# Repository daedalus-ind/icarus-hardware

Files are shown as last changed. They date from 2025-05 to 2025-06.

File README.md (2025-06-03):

# Icarus Flight Computer V1.0

This repository contains the hardware design files for the version 1.0 of the flight computer developed for Project Icarus, a model rocket.

## 📸 Photos

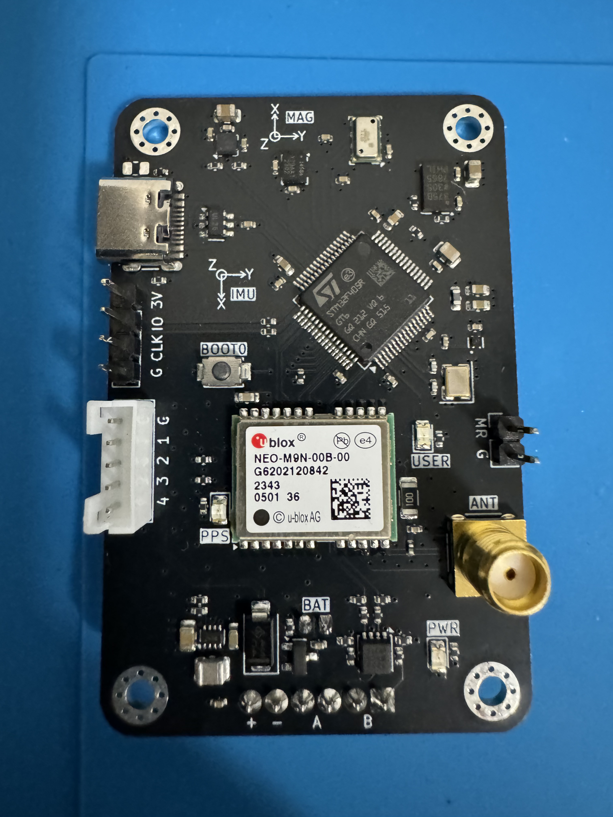
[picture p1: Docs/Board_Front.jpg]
Icarus Flight Computer V1.0 Front Size

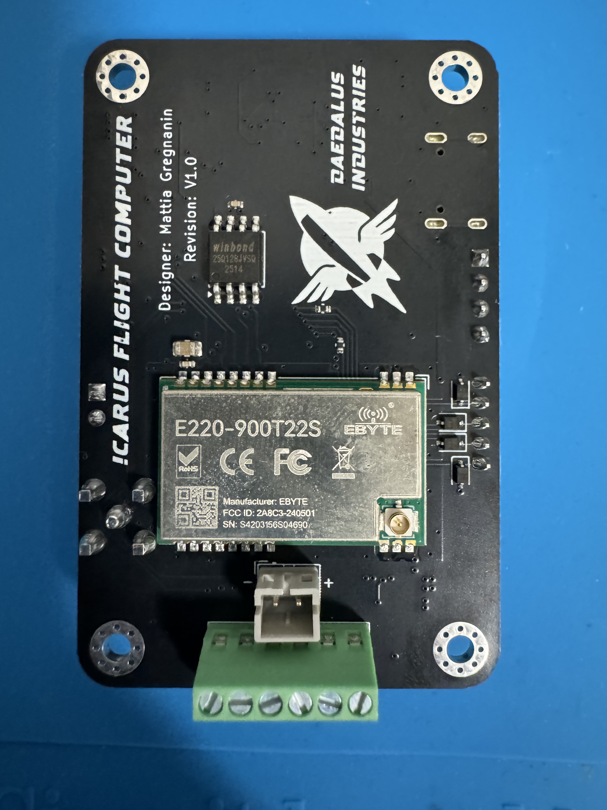
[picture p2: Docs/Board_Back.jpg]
Icarus Flight Computer V1.0 Back Side


## 🧰 Overview 

The Icarus Flight Computer V1.0 is designed to manage data acquisition, telemetry, and flight event control during rocket missions. The board includes:
- **Microcontroller**: STMicroelectronics STM32F405RGT6
- **6-Axis IMU**: TDK InvenSense ICM-45686
- **High-G Accelerometer**: Analog Devices ADXL375
- **Magnetometer**: STMicroelectronics LIS2MDL
- **Barometer**: MEAS MS5607
- **GPS Module**: u-blox NEO-M9N
- **Radio Module**: EBYTE E220-900T22S
- **Flash Memory**: Windbond W25Q128JV
- **E-matches**: 2x electric matches for recovery system deployment
- **Power Management**: TPS631000 buck-boost converter
- **Power Supply**: 1S LiPo battery or USB-C power input

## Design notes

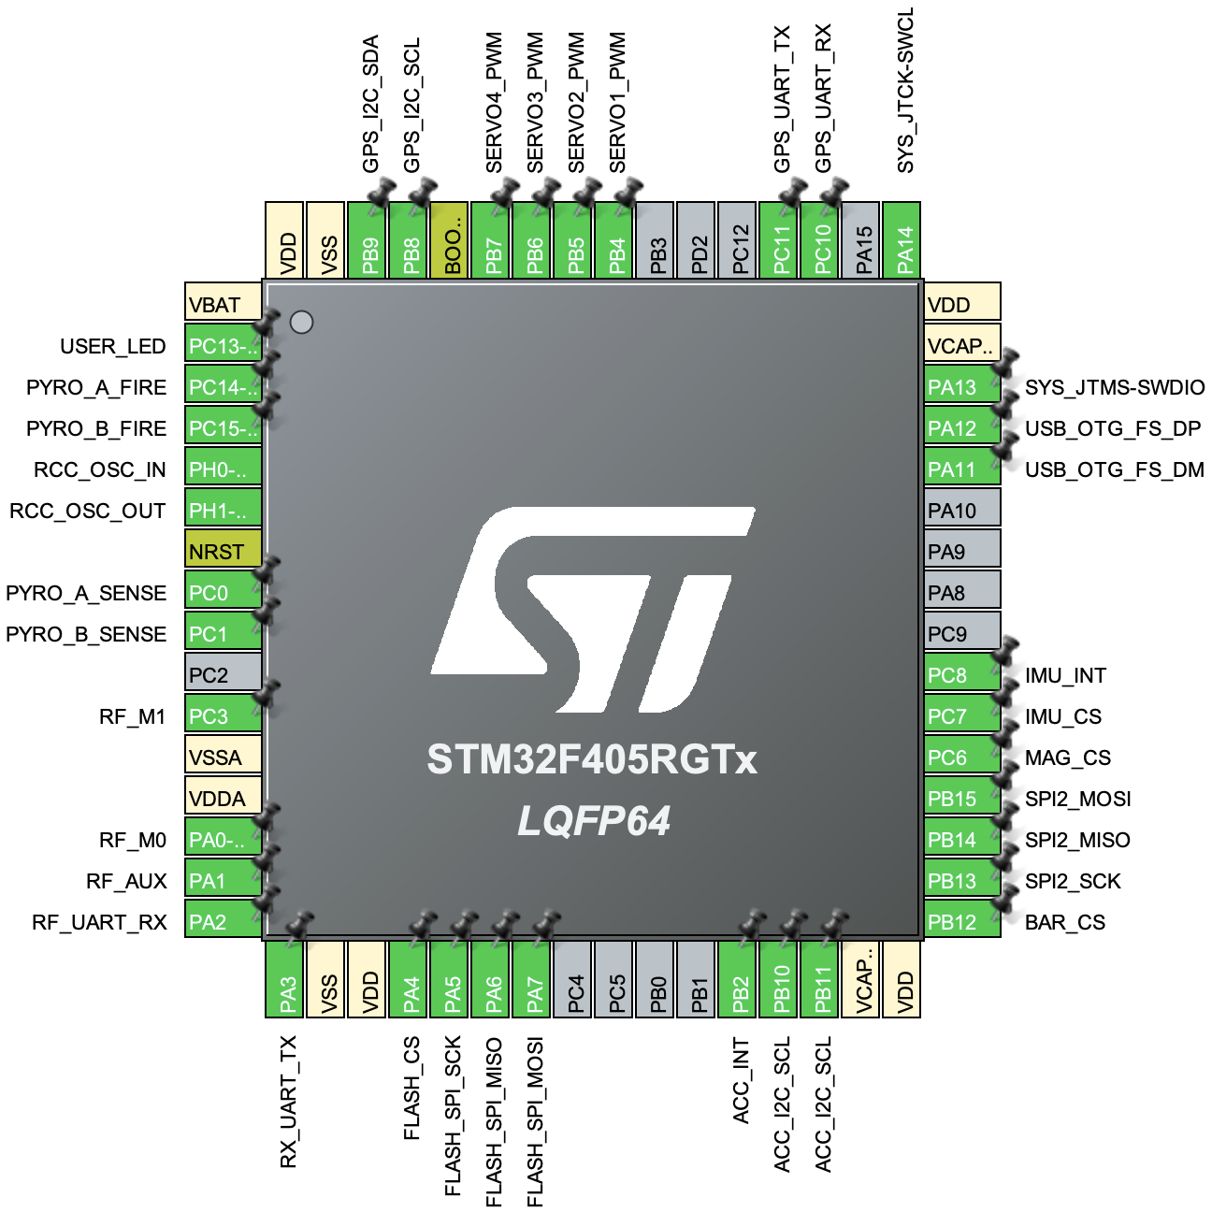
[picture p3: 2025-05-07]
STM32F405RGT6 Schematic.png

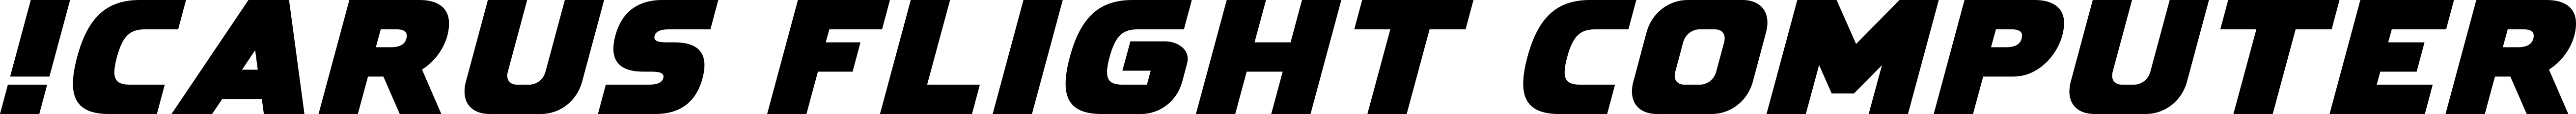
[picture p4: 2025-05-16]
IcarusFlightComputer-White-300dpi.png

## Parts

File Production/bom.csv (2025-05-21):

Designator | Footprint | Quantity | Value | LCSC Part #
C1, C23, C29, C35 | 0805 | 4 | 10u | C95841
C10, C15, C16, C17, C18, C2, C21, C22, C24, C25, C26, C27, C28, C3, C30, C31, C34, C36, C37, C4, C5, C6 | 0402 | 22 | 100n | C1525
C11, C12 | 0402 | 2 | 10p | C32949
C13, C14 | 0603 | 2 | 2u2 | C23630
C19 | 0805 | 1 | 47u | C471380
C20 | 0603 | 1 | 10u | C90053
C32 | 0402 | 1 | 220n | C16772
C33, C7, C8 | 0603 | 3 | 1u | C59782
C9 | 0402 | 1 | 10n | C318577
D1, D2, D4 | 0805 | 3 | RED | C84256
D3 | D_SMA | 1 | SS14 | C47460
D5, D6, D7, D8 | D_SOD-323 | 4 | PESD3V3L1BA | C51450
FB1 | 0603 | 1 | 120R | C85831
J1 | PinHeader_1x04_P2.54mm_Vertical | 1 | Conn_01x04_Pin | C2691448
J2 | USB_C_Receptacle_G-Switch_GT-USB-7010ASV | 1 | USB_C_Receptacle_USB2.0_14P | C2988369
J3 | JST_PH_B2B-PH-K_1x02_P2.00mm_Vertical | 1 | JST PH 2.0 | C2683610
J4 | PinHeader_1x02_P2.54mm_Vertical | 1 | Conn_01x02_Pin | C492401
J5 | SMA_Amphenol_132134_Vertical | 1 | SMA | C3174425
J6 | TerminalBlock_Phoenix_MPT-0,5-6-2.54_1x06_P2.54mm_Horizontal | 1 | Screw_Terminal_01x06 | C3817456
J7 | JST_PH_B5B-PH-K_1x05_P2.00mm_Vertical | 1 | JST PH 2.0 | C157993
L1 | 1008 | 1 | 1u | C882955
L2 | 0402 | 1 | 27n | C12669
Q1 | SOT-23 | 1 | DMG2305UX | C150470
Q2 | Vishay_PowerPAK_1212-8_Dual | 1 | Si7232DN | C144854
R1, R2 | 0402 | 2 | 22R | C25092
R10, R11 | 0402 | 2 | 5k1 | C25905
R13 | 0402 | 1 | 511k | C64042
R14, R18, R20, R24, R5 | 0402 | 5 | 1k | C11702
R15 | 0402 | 1 | 91k | C4147
R16, R19, R23 | 0402 | 3 | 100k | C25741
R17 | 1206 | 1 | 10R | C25349
R21, R25 | 0402 | 2 | 27k | C25771
R22, R26, R3, R4 | 0402 | 4 | 10k | C25531
R27, R28, R29, R30 | 0402 | 4 | 47R | C25118
R6, R7, R8, R9 | 0402 | 4 | 2k | C4109
SW1 | SW_TS-1088-AR02016 | 1 | SW_Push | C720477
U1 | LQFP-64_10x10mm_P0.5mm | 1 | STM32F405RGT6 | C15742
U10 | ublox_NEO | 1 | NEO-M9N-00B | C5119087
U11 | E220-xxxT22S | 1 | E220-900T22S | C970285
U2 | SOIC-8_5.3x5.3mm_P1.27mm | 1 | W25Q128JVSIQ | C97521
U3 | SOT-23-6 | 1 | USBLC6-2SC6 | C7519
U4 | Texas_X2SON-4_1x1mm_P0.65mm | 1 | TPS3831G33DQNR | C2066649
U5 | SOT-583-8 | 1 | TPS631000 | C5219190
U6 | LGA-14_3x2.5mm_P0.5mm_LayoutBorder3x4y | 1 | ICM-45686 | C22459454
U7 | LGA-14_3x5mm_P0.8mm_LayoutBorder1x6y | 1 | ADXL375 | C579466
U8 | LGA-12_2x2mm_P0.5mm | 1 | LIS2MDL | C919695
U9 | MS5607-02BA03 | 1 | MS5607-02BA | C97627
Y1 | Crystal_SMD_3225-4Pin_3.2x2.5mm | 1 | 16MHz | C112972

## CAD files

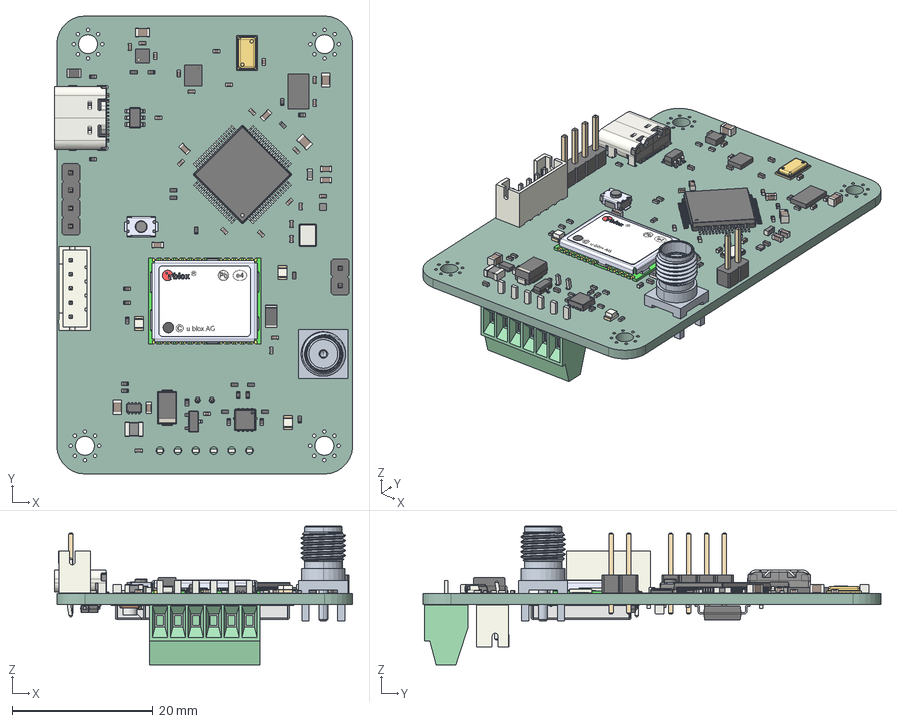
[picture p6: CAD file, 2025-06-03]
Docs/Icarus Flight Computer.step
42.4 x 65.0 x 19.7 mm
R_0402_1005Metric x 28
R_0805_2012Metric
NEO_PCB
Shield_NEO
u-blox_NEO_label
C_0603_1608Metric x 6
C_0402_1005Metric x 26
LGA-14_3x2.5mm_P0.5mm_LayoutBorder3x4y
LED_0805_2012Metric x 3
L_0603_1608Metric
PowerPAK_1212_Dual
LGA-14_3x5mm_P0.8mm_LayoutBorder1x6y
Crystal_SMD_3225-4Pin_3.2x2.5mm
L_1008_2520Metric
R_1206_3216Metric
C_0805_2012Metric x 5
SOT-23-6
SOT-583-8
D_SMA
SOT-23
L_0402_1005Metric
TS-1088-AR02016
PinHeader_1x02_P2.54mm_Vertical
PinHeader_1x04_P2.54mm_Vertical
JST_PH_B5B-PH-K_1x05_P2.00mm_Vertical
Texas_X2SON-4_1x1mm_P0.65mm
SMA_Amphenol_132134
LGA-12_2x2mm_P0.5mm
LQFP-64_10x10mm_P0.5mm
Imported
USB_C_Receptacle_GCT_USB4105-xx-A_16P_TopMnt_Horizontal
D_SOD-323 x 4
Board
CAPC1005X56N_EIA_0402 x 35
User_Library-RESC0603X___ x 7
R0402 x 7
User_Library-SOT23-5_SOT23-5_Connector_Default x 10
User_Library-SOT23-5_SOT23-5_Body_Default x 2
User_Library-GeyerElectronics_KX7
User_Library-Chip_InductorINDC1005X60N x 8
INDC2012X105N_EIA_0805
CAPC1608X92N_EIA_0603 x 2
ANT-IPEX-1
PBZ-43
JST_PH_B2B-PH-K_1x02_P2.00mm_Vertical
TerminalBlock_Phoenix_MPT-0,5-6-2.54_1x06_P2.54mm_Horizontal
SOIC-8_5.3x5.3mm_P1.27mm
Icarus Flight Computer_PCB

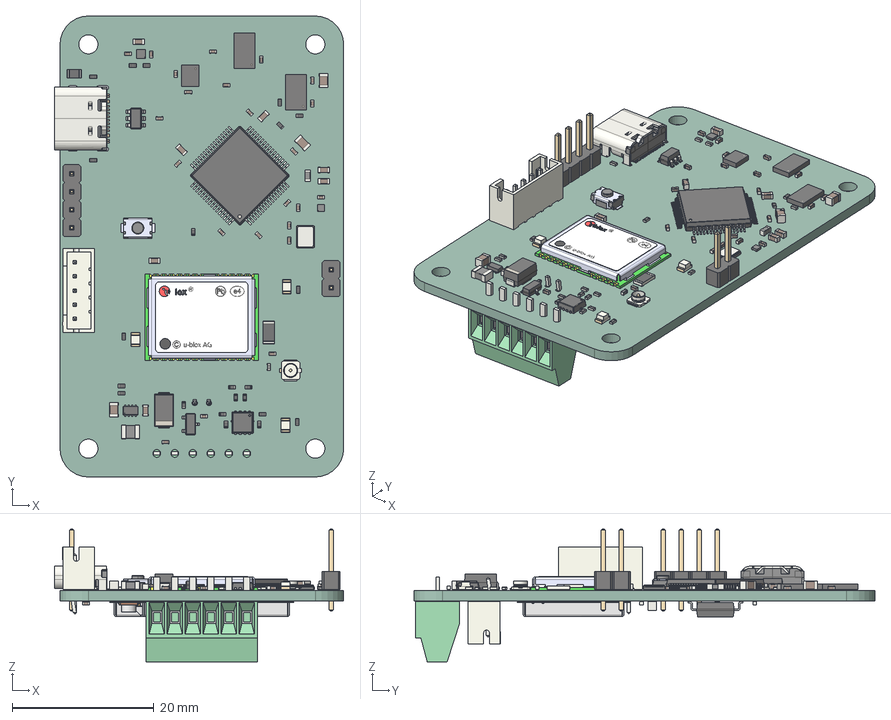
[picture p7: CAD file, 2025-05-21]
Icarus Flight Computer.step
40.8 x 65.0 x 18.7 mm
R_0805_2012Metric
NEO_PCB
Shield_NEO
u-blox_NEO_label
C_0603_1608Metric x 7
C_0402_1005Metric x 26
LGA-14_3x2.5mm_P0.5mm_LayoutBorder3x4y
LED_0805_2012Metric x 3
R_0402_1005Metric x 22
L_0603_1608Metric
PowerPAK_1212_Dual
LGA-14_3x5mm_P0.8mm_LayoutBorder1x6y
Crystal_SMD_3225-4Pin_3.2x2.5mm
L_1008_2520Metric
R_1206_3216Metric
C_0805_2012Metric x 4
SOT-23-6
SOT-583-8
D_SMA
SOT-23
L_0402_1005Metric
TS-1088-AR02016
PinHeader_1x02_P2.54mm_Vertical
PinHeader_1x04_P2.54mm_Vertical
Texas_X2SON-4_1x1mm_P0.65mm
U.FL_Hirose_U.FL-R-SMT-1_Vertical
BGA9_BMM350_BOS
LQFP-64_10x10mm_P0.5mm
LGA-8_3x5mm_P1.25mm
USB_C_Receptacle_GCT_USB4105-xx-A_16P_TopMnt_Horizontal
JST_PH_B5B-PH-K_1x05_P2.00mm_Vertical
Board
CAPC1005X56N_EIA_0402 x 35
User_Library-RESC0603X___ x 7
R0402 x 7
User_Library-SOT23-5_SOT23-5_Connector_Default x 10
User_Library-SOT23-5_SOT23-5_Body_Default x 2
User_Library-GeyerElectronics_KX7
User_Library-Chip_InductorINDC1005X60N x 8
INDC2012X105N_EIA_0805
CAPC1608X92N_EIA_0603 x 2
ANT-IPEX-1
PBZ-43
JST_PH_B2B-PH-K_1x02_P2.00mm_Vertical
TerminalBlock_Phoenix_MPT-0,5-6-2.54_1x06_P2.54mm_Horizontal
SOIC-8_5.3x5.3mm_P1.27mm
Icarus Flight Computer_PCB

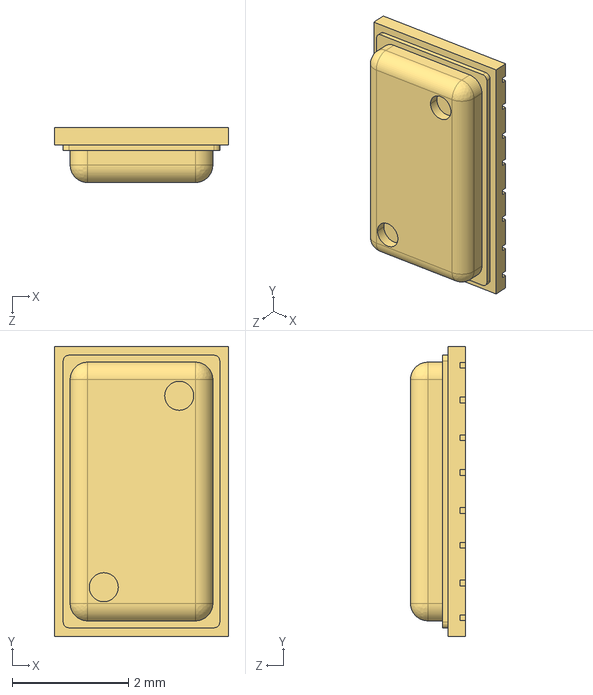
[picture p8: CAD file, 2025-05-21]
Models/MS5607-02BA03.STEP
3.00 x 5.00 x 0.95 mm

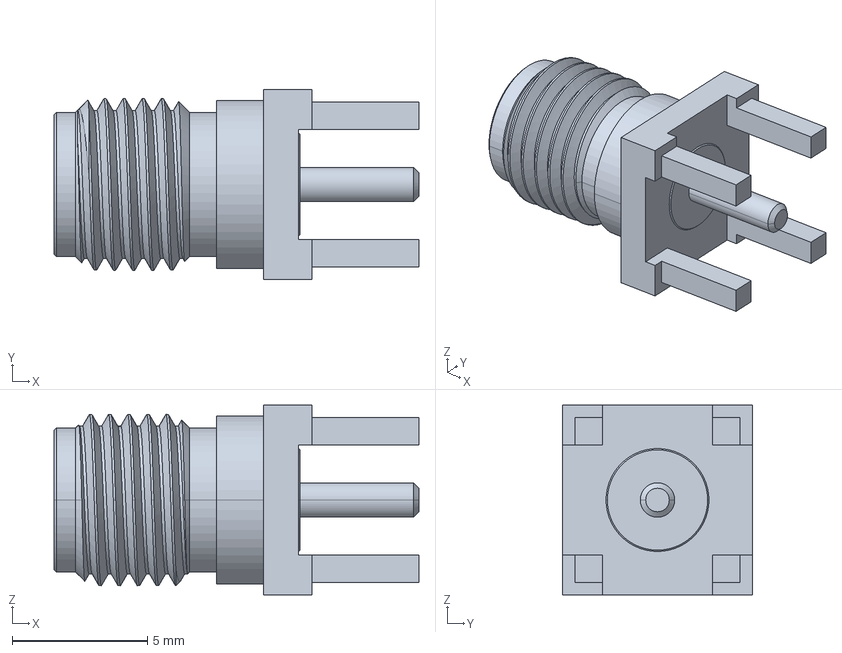
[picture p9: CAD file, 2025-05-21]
Models/SMA_Amphenol_132134.stp
13.5 x 7.00 x 7.00 mm

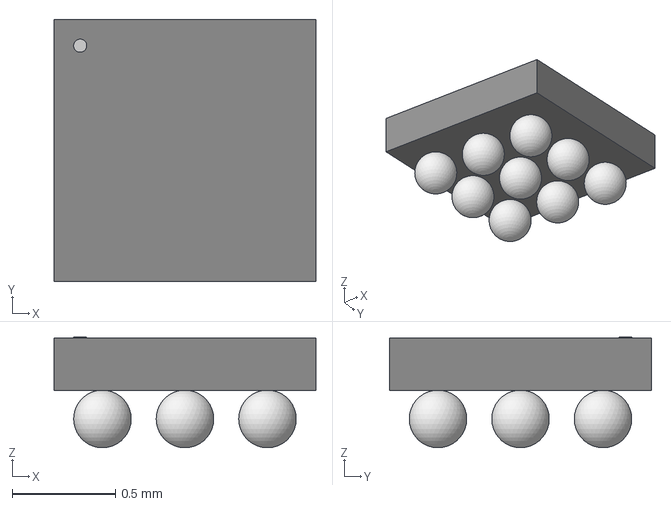
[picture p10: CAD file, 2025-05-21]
Models/BGA9_BMM350_BOS.step
1.27 x 1.27 x 0.536 mm

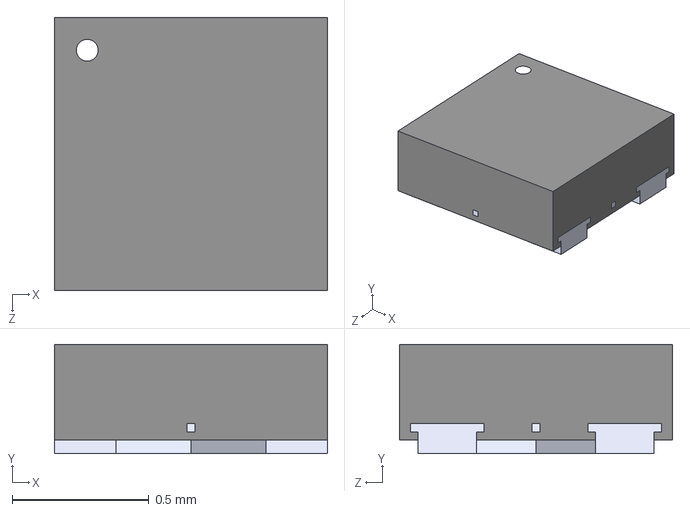
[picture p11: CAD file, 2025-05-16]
Models/Texas_X2SON-4_1x1mm_P0.65mm.step
1.00 x 0.4 x 1.00 mm

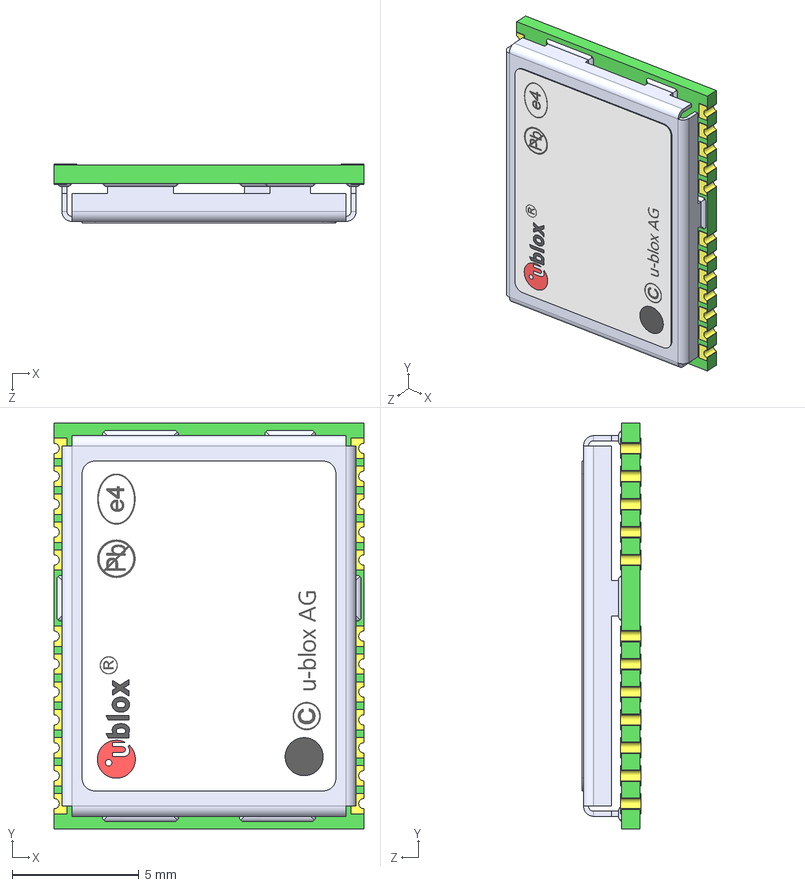
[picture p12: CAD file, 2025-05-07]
Models/NEO.STEP
12.2 x 16.0 x 2.33 mm
NEO_PCB
Shield_NEO
u-blox_NEO_label

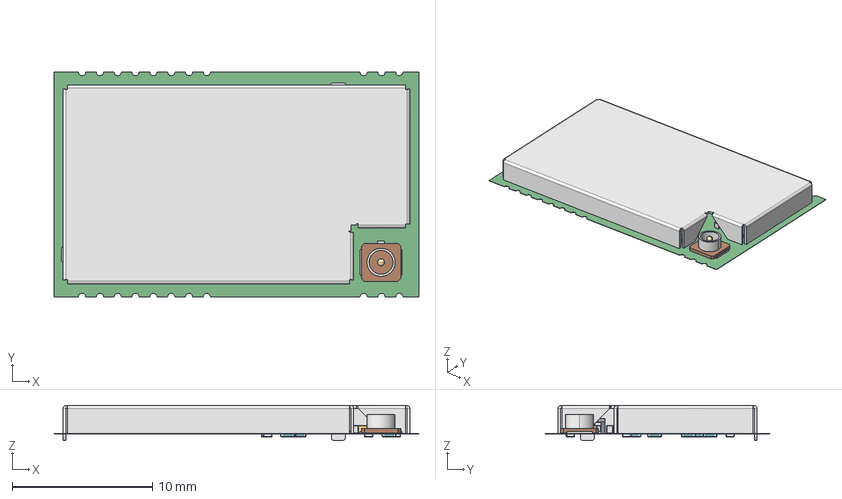
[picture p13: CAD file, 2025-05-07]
Models/E220-xxxT22S.step
26.0 x 16.0 x 2.50 mm
Board
CAPC1005X56N_EIA_0402 x 35
User_Library-RESC0603X___ x 7
R0402 x 7
User_Library-SOT23-5_SOT23-5_Connector_Default x 10
User_Library-SOT23-5_SOT23-5_Body_Default x 2
User_Library-GeyerElectronics_KX7
User_Library-Chip_InductorINDC1005X60N x 8
INDC2012X105N_EIA_0805
CAPC1608X92N_EIA_0603 x 2
ANT-IPEX-1
PBZ-43

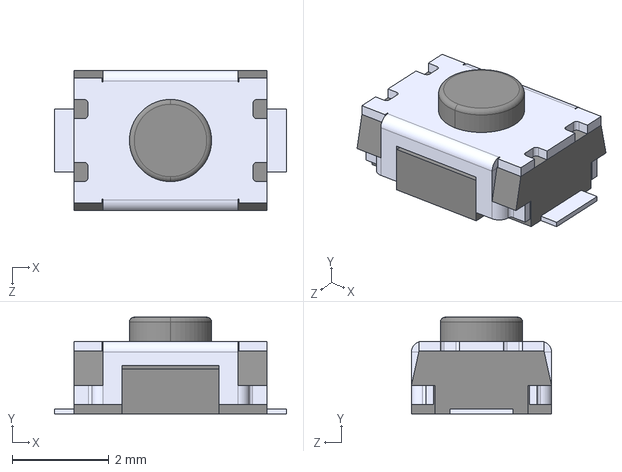
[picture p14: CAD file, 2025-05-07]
Models/TS-1088-AR02016.STEP
4.80 x 2.00 x 2.90 mm

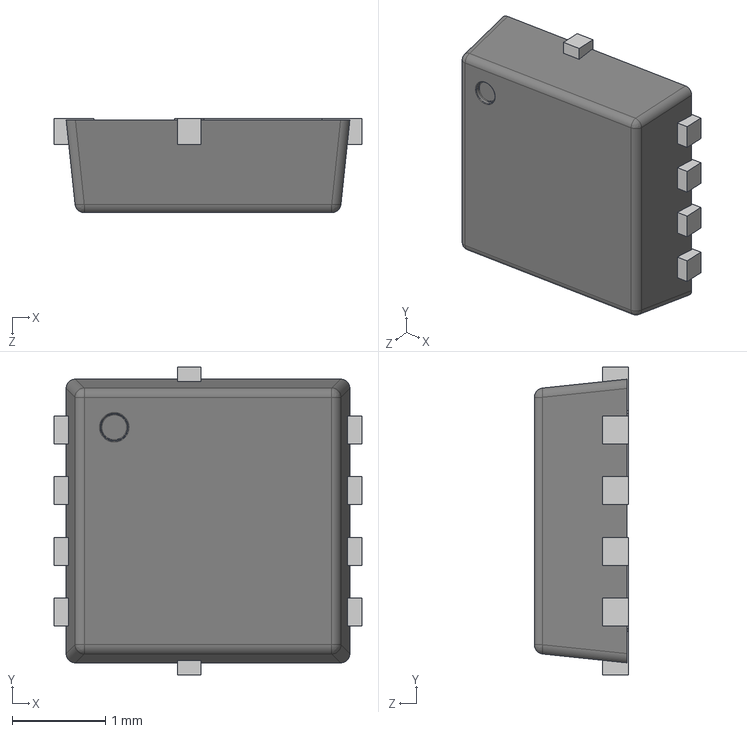
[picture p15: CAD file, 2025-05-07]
Models/PowerPAK_1212_Dual.step
3.30 x 3.30 x 1.01 mm

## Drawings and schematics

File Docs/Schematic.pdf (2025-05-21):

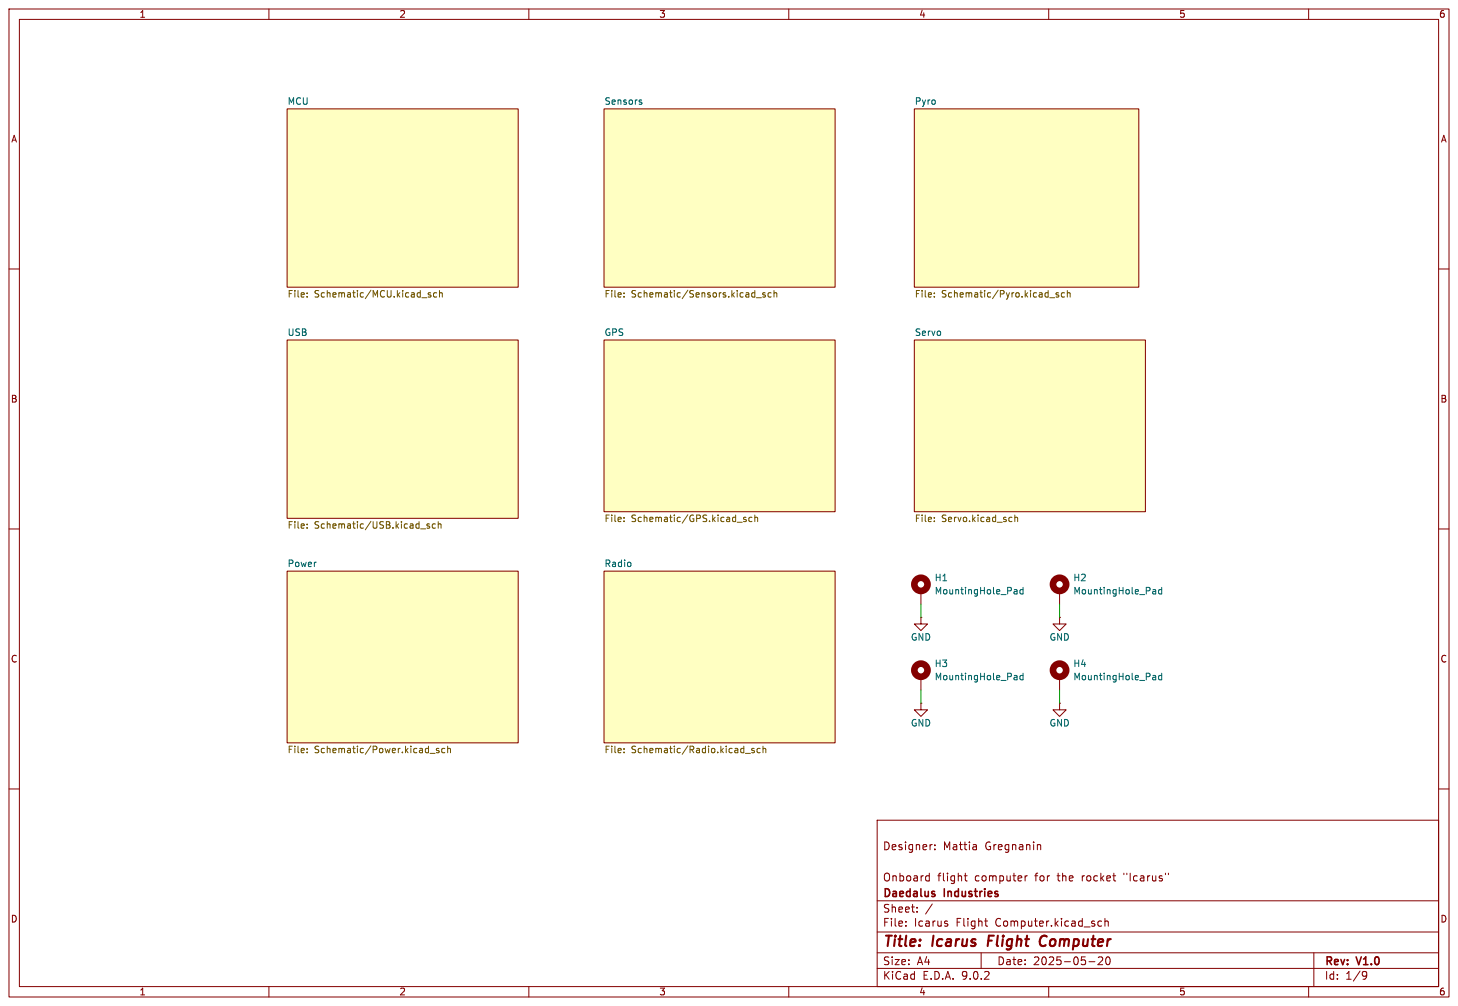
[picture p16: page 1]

Servo File: Servo.kicad_sch Pyro File: Schematic/Pyro.kicad_sch MCU
File: Schematic/MCU.kicad_sch Power File: Schematic/Power.kicad_sch

Sensors File: Schematic/Sensors.kicad_sch GPS

File: Schematic/GPS.kicad_sch USB

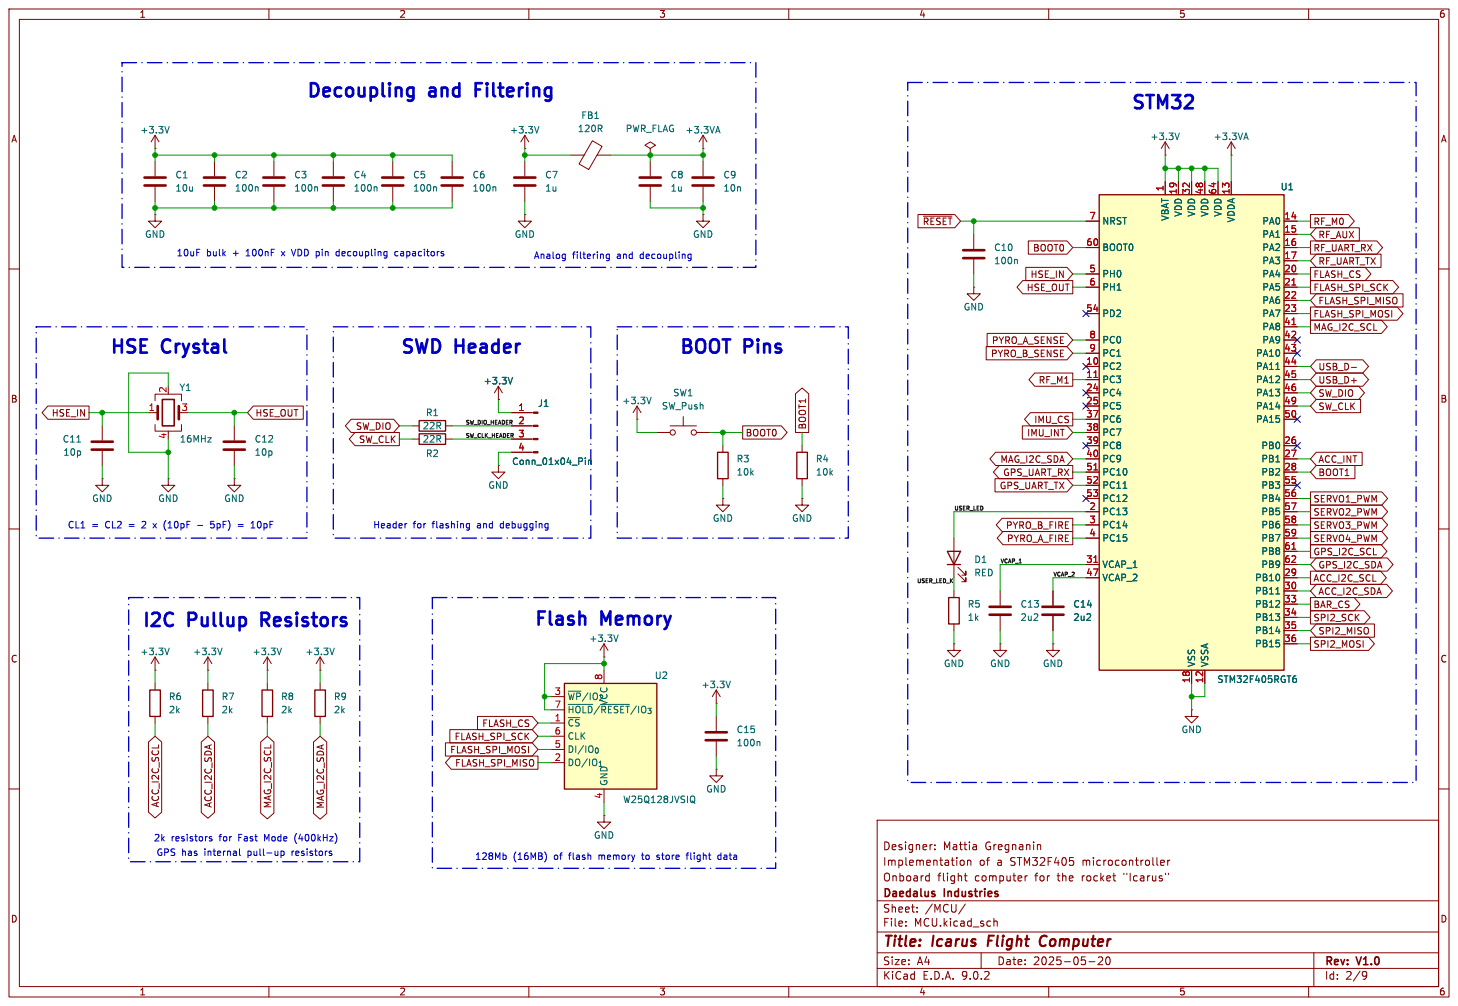
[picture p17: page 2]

1 VDD 19 VDD 32 VSS 18 VDD 48 VSSA 12 VDD 64 VDDA 13 PA0 14 PA1 15 PA2 16 PA3 17 PA4 20 PA5 21 PA6 22 PA7 23 PA8 41 PA9 42 PA10 43 PA11 44 PA12 45 PA13 46 PA14 49 PA15 50 PB0 26 PB1 27 PB2 28 PB3 55 PB4 56 PB5 57 PB6 58 PB7 59 PB8 61 PB9 62 PB10 29 PB11 30 PB12 33 PB13 34 PB14 35 PB15 36 U1 STM32F405RGT6

1 VDD 19 VDD 32 VSS 18 VDD 48 VSSA 12 VDD 64 VDDA 13 PA0 14 PA1 15 PA2 16 PA3 17 PA4 20 PA5 21 PA6 22 PA7 23 PA8 41 PA9 42 PA10 43 PA11 44 PA12 45 PA13 46 PA14 49 PA15 50 PB0 26 PB1 27 PB2 28 PB3 55 PB4 56 PB5 57 PB6 58 PB7 59 PB8 61 PB9 62 PB10 29 PB11 30 PB12 33 PB13 34 PB14 35 PB15 36 C14

128Mb (16MB) of flash memory to store flight data BOOT Pins
+3.3V GND

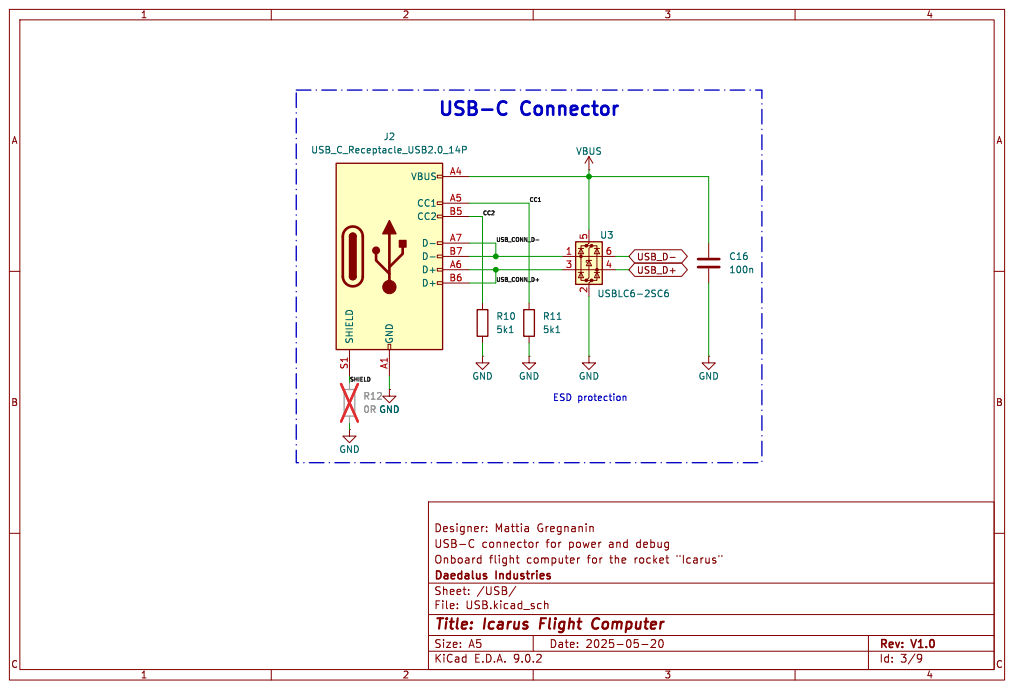
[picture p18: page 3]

Sheet: /USB/
Title: Icarus Flight Computer

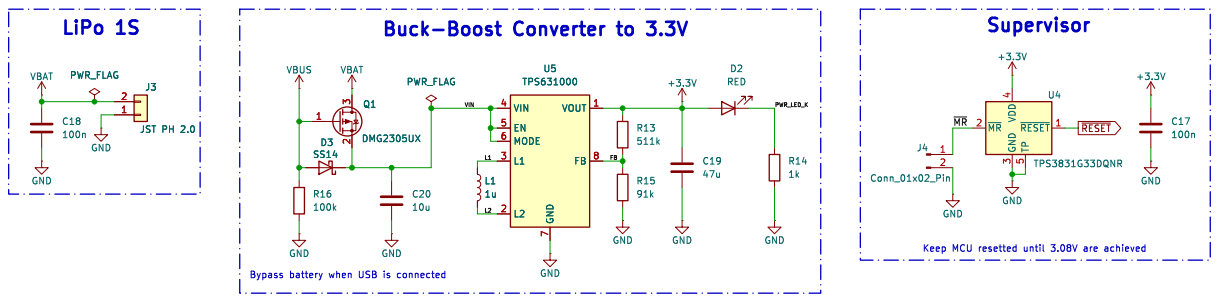
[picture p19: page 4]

Keep MCU resetted until 3.08V are achieved LiPo 1S

Bypass battery when USB is connected

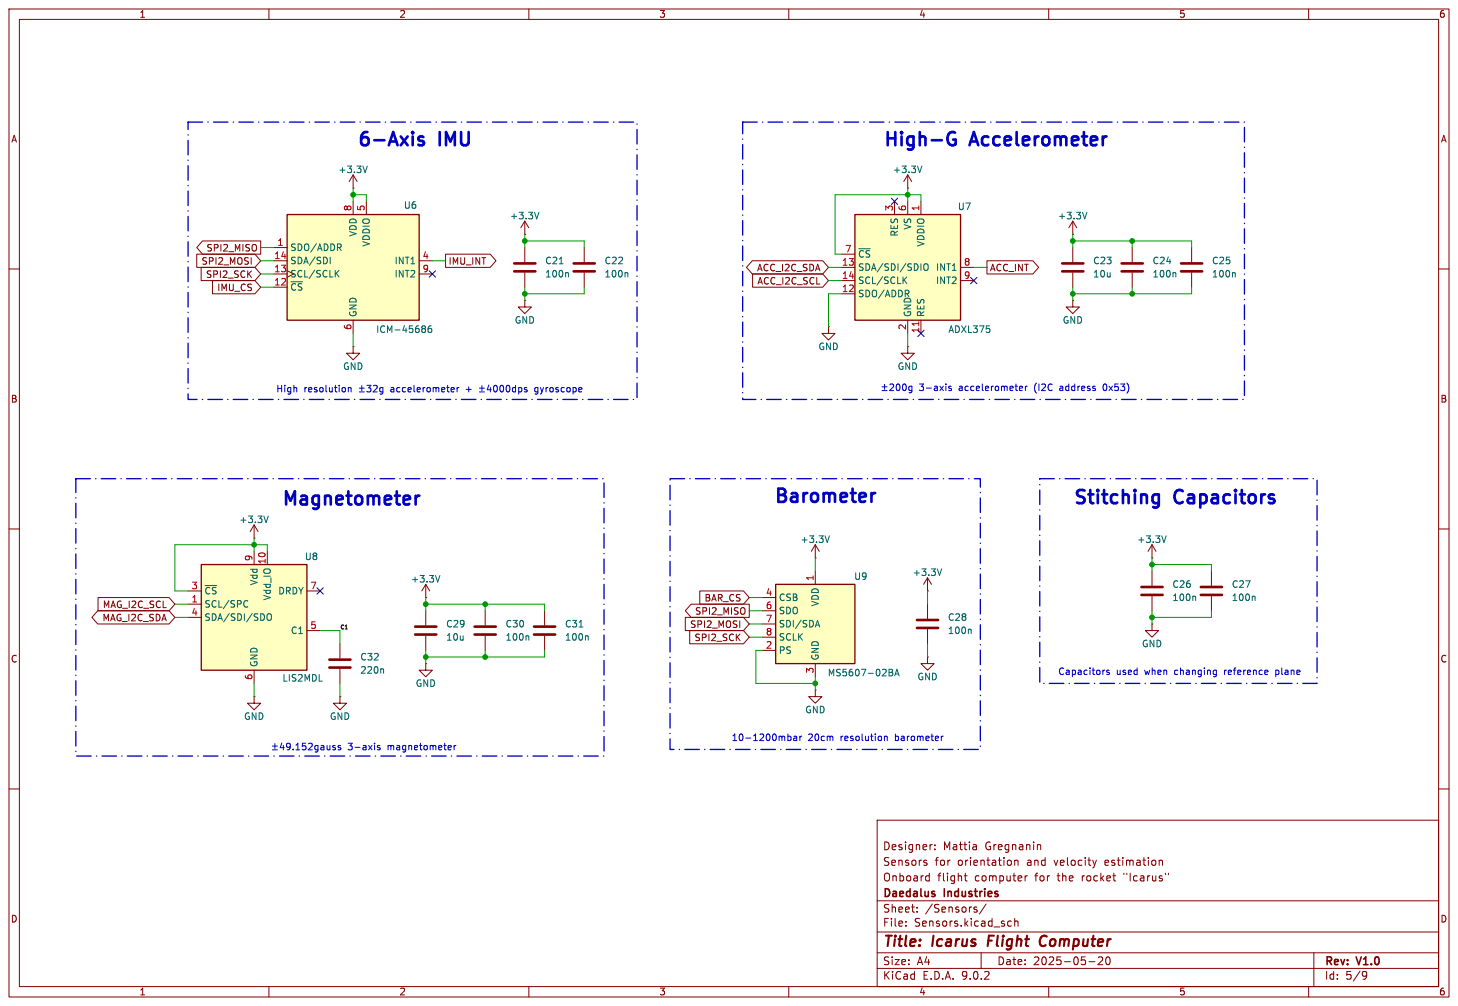
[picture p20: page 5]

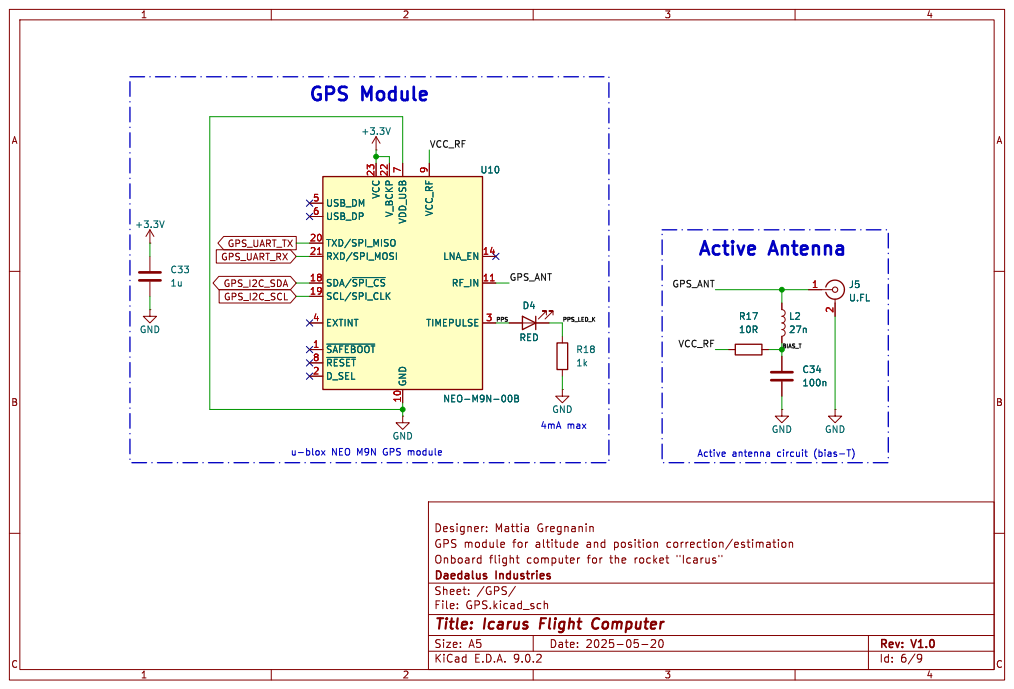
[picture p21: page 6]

Sheet: /GPS/
File: GPS.kicad_sch
Title: Icarus Flight Computer

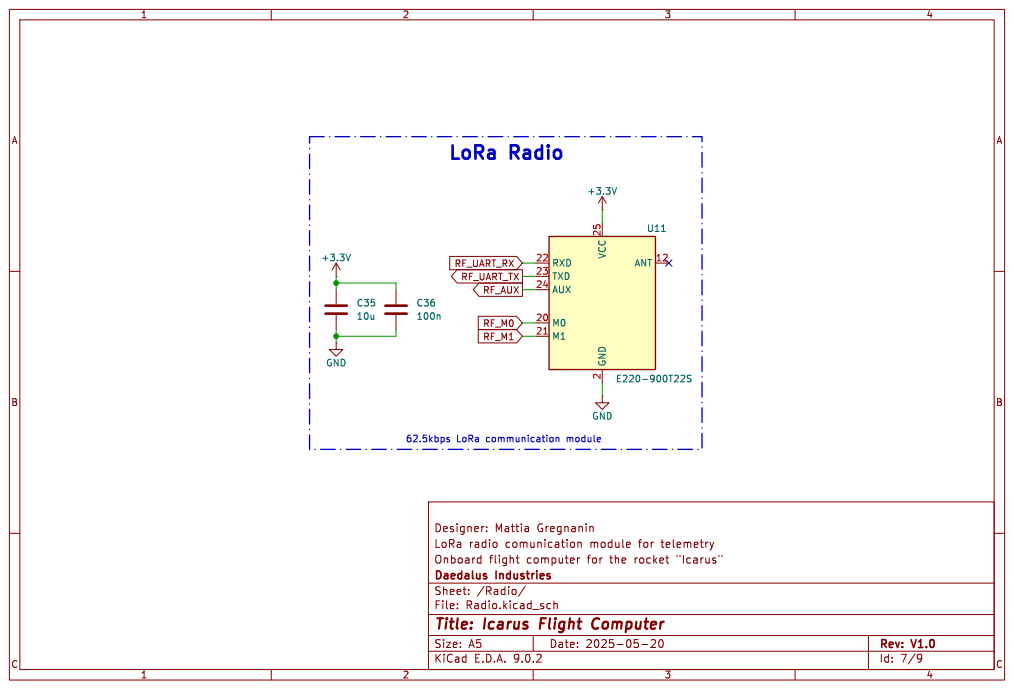
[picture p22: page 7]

Sheet: /Radio/
Title: Icarus Flight Computer

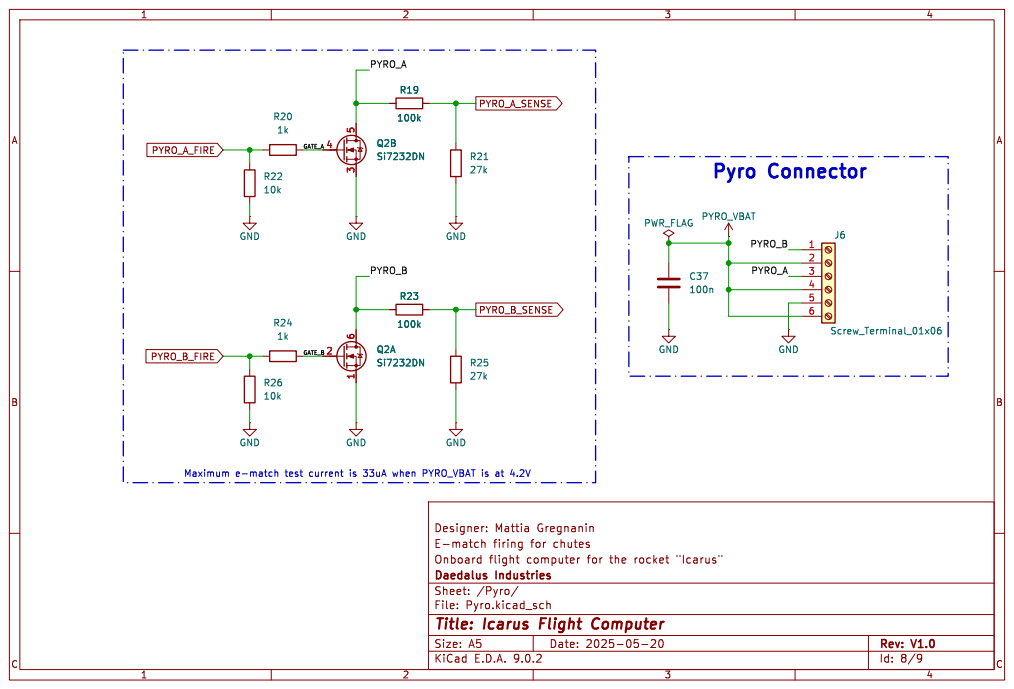
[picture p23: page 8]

Sheet: /Pyro/
Title: Icarus Flight Computer

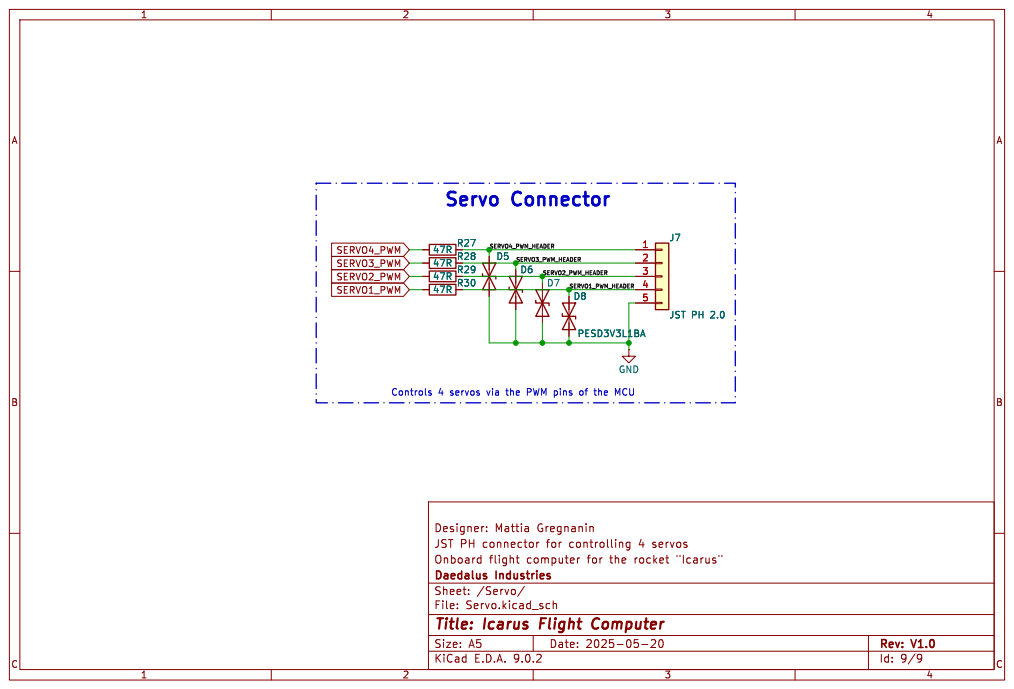
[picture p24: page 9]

47R
R28 47R
R30 47R

Sheet: /Servo/
File: Servo.kicad_sch
Title: Icarus Flight Computer

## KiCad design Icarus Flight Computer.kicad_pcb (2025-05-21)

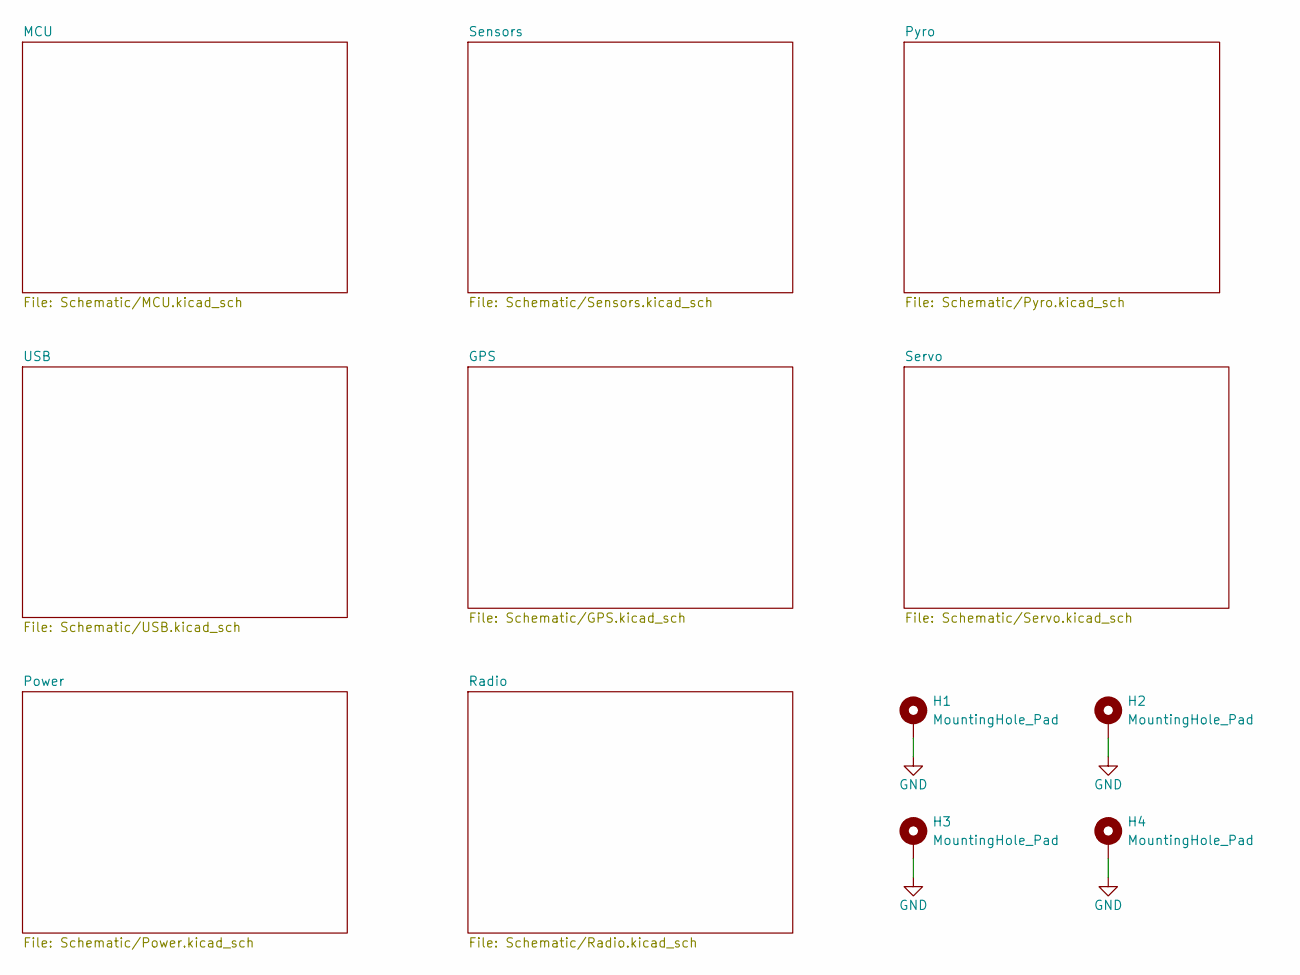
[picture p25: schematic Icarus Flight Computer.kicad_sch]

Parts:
H1, H2, H3, H4: MountingHole_Pad; MountingHole_2.7mm_M2.5_Pad_Via

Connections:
GND: H1.1, H2.1, H3.1, H4.1; also elsewhere on the board

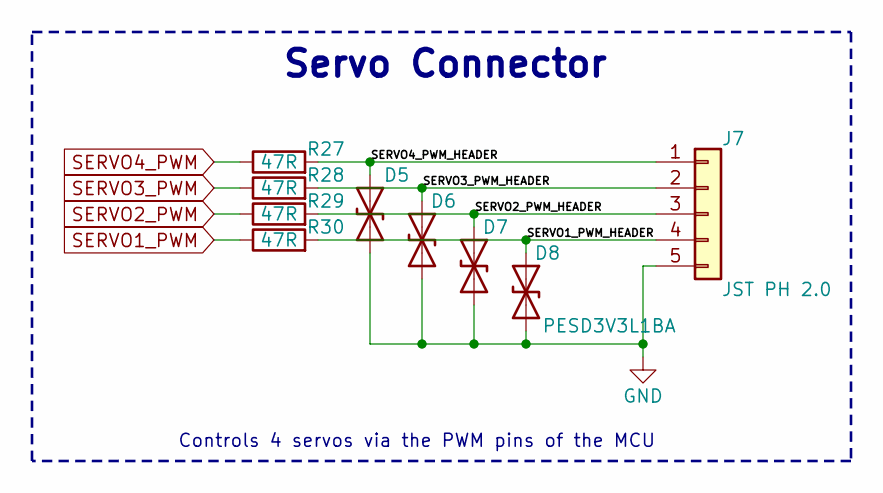
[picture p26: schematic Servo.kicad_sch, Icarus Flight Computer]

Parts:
D5, D6, D7, D8: PESD3V3L1BA; D_SOD-323; MPN C51450
J7: JST PH 2.0; JST_PH_B5B-PH-K_1x05_P2.00mm_Vertical; MPN C157993
R27, R28, R29, R30: 47R; R_0402_1005Metric; MPN C25118

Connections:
/Servo/SERVO1_PWM_HEADER: D8.1 (A1), J7.4, R30.2
/Servo/SERVO2_PWM_HEADER: D7.1 (A1), J7.3, R29.2
/Servo/SERVO3_PWM_HEADER: D6.1 (A1), J7.2, R28.2
/Servo/SERVO4_PWM_HEADER: D5.1 (A1), J7.1, R27.2
GND: D5.2 (A2), D6.2 (A2), D7.2 (A2), D8.2 (A2), J7.5; also elsewhere on the board
SERVO1_PWM: R30.1; also elsewhere on the board
SERVO2_PWM: R29.1; also elsewhere on the board
SERVO3_PWM: R28.1; also elsewhere on the board
SERVO4_PWM: R27.1; also elsewhere on the board

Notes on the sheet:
Servo Connector
Controls 4 servos via the PWM pins of the MCU

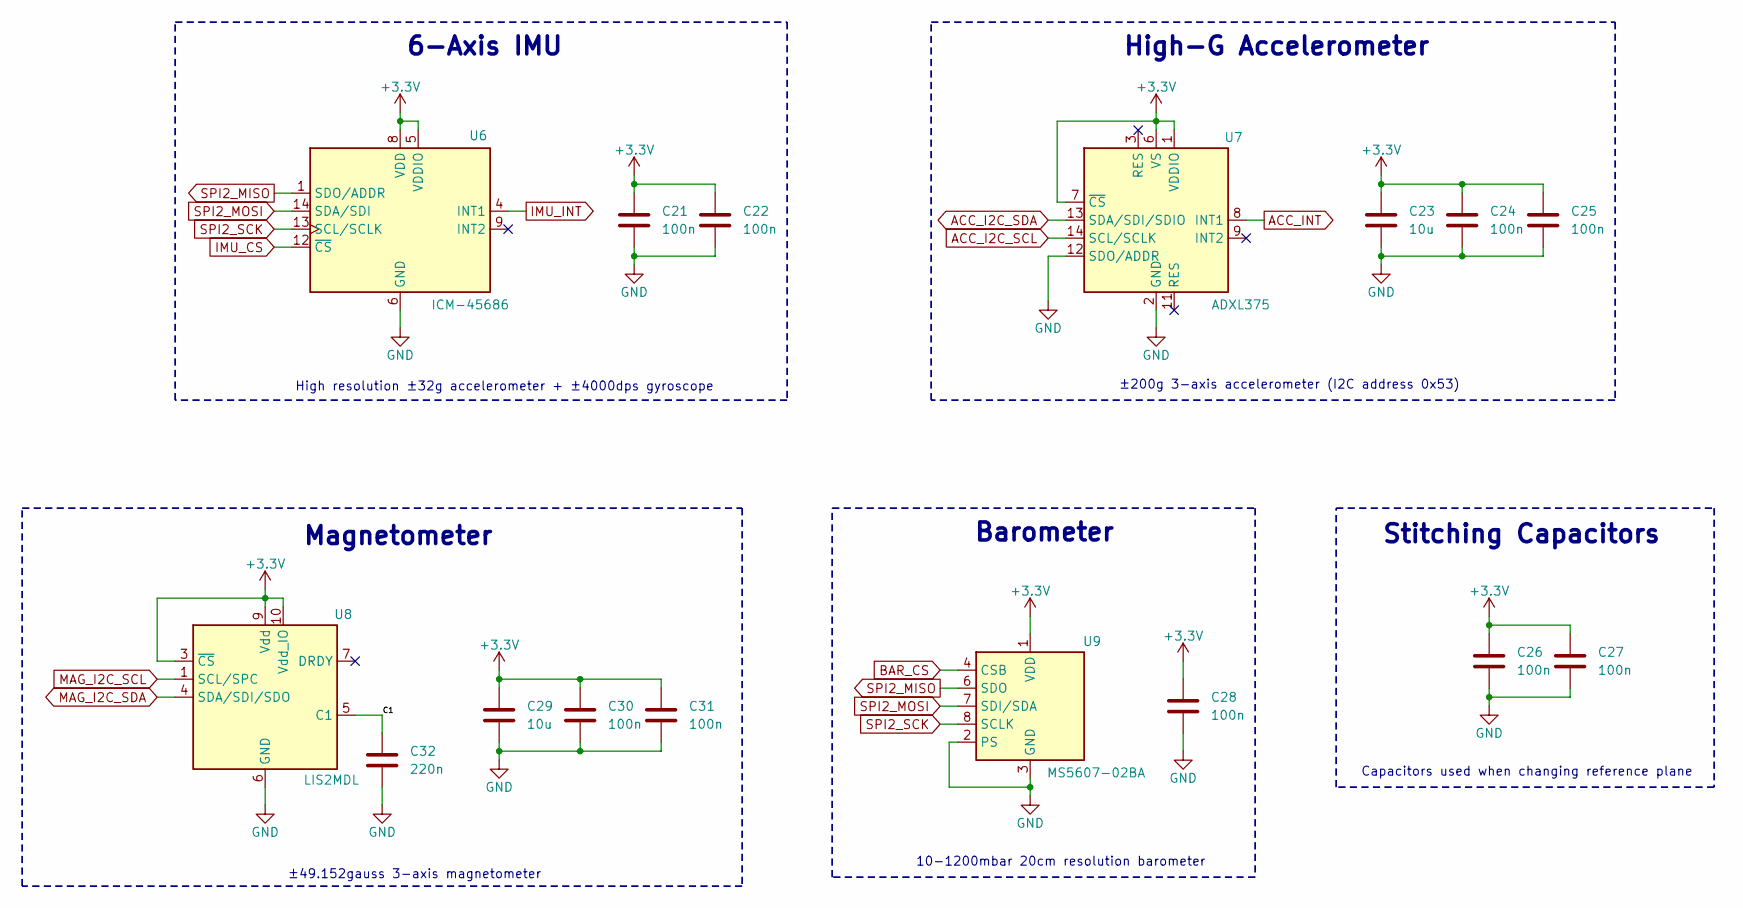
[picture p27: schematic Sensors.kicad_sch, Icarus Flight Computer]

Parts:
C21, C22, C24, C25, C26, C27, C28, C30, C31: 100n; C_0402_1005Metric; MPN C1525
C23, C29: 10u; C_0805_2012Metric; MPN C95841
C32: 220n; C_0402_1005Metric; MPN C16772
U6: ICM-45686; LGA-14_3x2.5mm_P0.5mm_LayoutBorder3x4y; MPN C22459454
U7: ADXL375; LGA-14_3x5mm_P0.8mm_LayoutBorder1x6y; MPN C579466
U8: LIS2MDL; LGA-12_2x2mm_P0.5mm; MPN C919695
U9: MS5607-02BA; MS5607-02BA03; MPN C97627

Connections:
+3.3V: C21.1, C22.1, C23.1, C24.1, C25.1, C26.1, C27.1, C28.1, C29.1, C30.1, C31.1, U6.5 (VDDIO), U6.8 (VDD), U7.1 (VDDIO), U7.6 (VS), U7.7 (~CS), U8.3 (~CS), U8.9 (Vdd), U8.10 (Vdd_IO), U9.1 (VDD); also elsewhere on the board
/Sensors/C1: C32.1, U8.5 (C1)
ACC_I2C_SCL: U7.14 (SCL/SCLK); also elsewhere on the board
ACC_I2C_SDA: U7.13 (SDA/SDI/SDIO); also elsewhere on the board
ACC_INT: U7.8 (INT1); also elsewhere on the board
BAR_CS: U9.4 (CSB), U9.5 (CSB); also elsewhere on the board
GND: C21.2, C22.2, C23.2, C24.2, C25.2, C26.2, C27.2, C28.2, C29.2, C30.2, C31.2, C32.2, U6.6 (GND), U7.2 (GND), U7.4 (GND), U7.5 (GND), U7.12 (SDO/ADDR), U8.6 (GND), U8.8 (GND), U9.2 (PS), U9.3 (GND); also elsewhere on the board
IMU_CS: U6.12 (~CS); also elsewhere on the board
IMU_INT: U6.4 (INT1); also elsewhere on the board
MAG_I2C_SCL: U8.1 (SCL/SPC); also elsewhere on the board
MAG_I2C_SDA: U8.4 (SDA/SDI/SDO); also elsewhere on the board
SPI2_MISO: U6.1 (SDO/ADDR), U9.6 (SDO); also elsewhere on the board
SPI2_MOSI: U6.14 (SDA/SDI), U9.7 (SDI/SDA); also elsewhere on the board
SPI2_SCK: U6.13 (SCL/SCLK), U9.8 (SCLK); also elsewhere on the board

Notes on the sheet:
±49.152gauss 3-axis magnetometer
Barometer
±200g 3-axis accelerometer (I2C address 0x53)
10-1200mbar 20cm resolution barometer
Magnetometer
High-G Accelerometer
6-Axis IMU
Capacitors used when changing reference plane
High resolution ±32g accelerometer + ±4000dps gyroscope
Stitching Capacitors

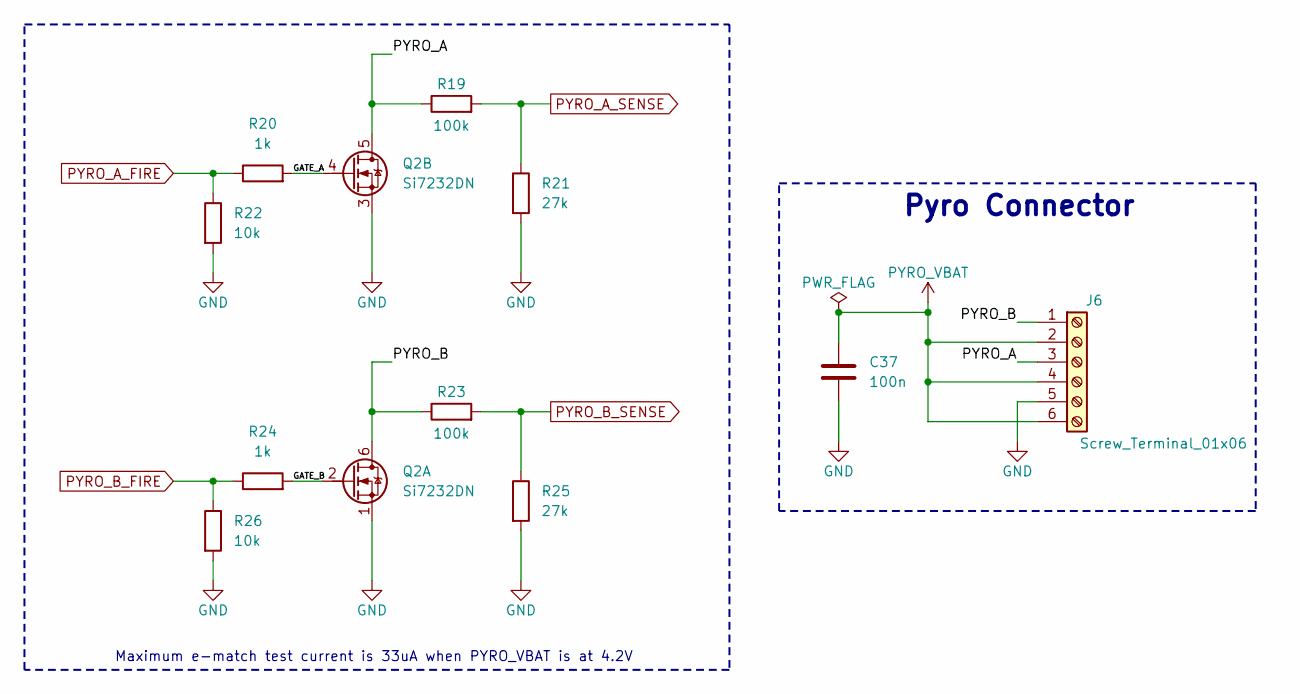
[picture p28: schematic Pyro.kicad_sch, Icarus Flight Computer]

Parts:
C37: 100n; C_0402_1005Metric; MPN C1525
J6: Screw_Terminal_01x06; TerminalBlock_Phoenix_MPT-0,5-6-2.54_1x06_P2.54mm_Horizontal; MPN C3817456
Q2: Si7232DN; Vishay_PowerPAK_1212-8_Dual; MPN C144854
R19, R23: 100k; R_0402_1005Metric; MPN C25741
R20, R24: 1k; R_0402_1005Metric; MPN C11702
R21, R25: 27k; R_0402_1005Metric; MPN C25771
R22, R26: 10k; R_0402_1005Metric; MPN C25531

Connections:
/Pyro/GATE_A: Q2.4 (G), R20.2
/Pyro/GATE_B: Q2.2 (G), R24.2
/Pyro/PYRO_A: J6.3, Q2.5 (D), R19.1
/Pyro/PYRO_B: J6.1, Q2.6 (D), R23.1
GND: C37.2, J6.5, Q2.1 (S), Q2.3 (S), R21.2, R22.2, R25.2, R26.2; also elsewhere on the board
PYRO_A_FIRE: R20.1, R22.1; also elsewhere on the board
PYRO_A_SENSE: R19.2, R21.1; also elsewhere on the board
PYRO_B_FIRE: R24.1, R26.1; also elsewhere on the board
PYRO_B_SENSE: R23.2, R25.1; also elsewhere on the board
PYRO_VBAT: C37.1, J6.2, J6.4, J6.6

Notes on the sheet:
Maximum e-match test current is 33uA when PYRO_VBAT is at 4.2V
Pyro Connector

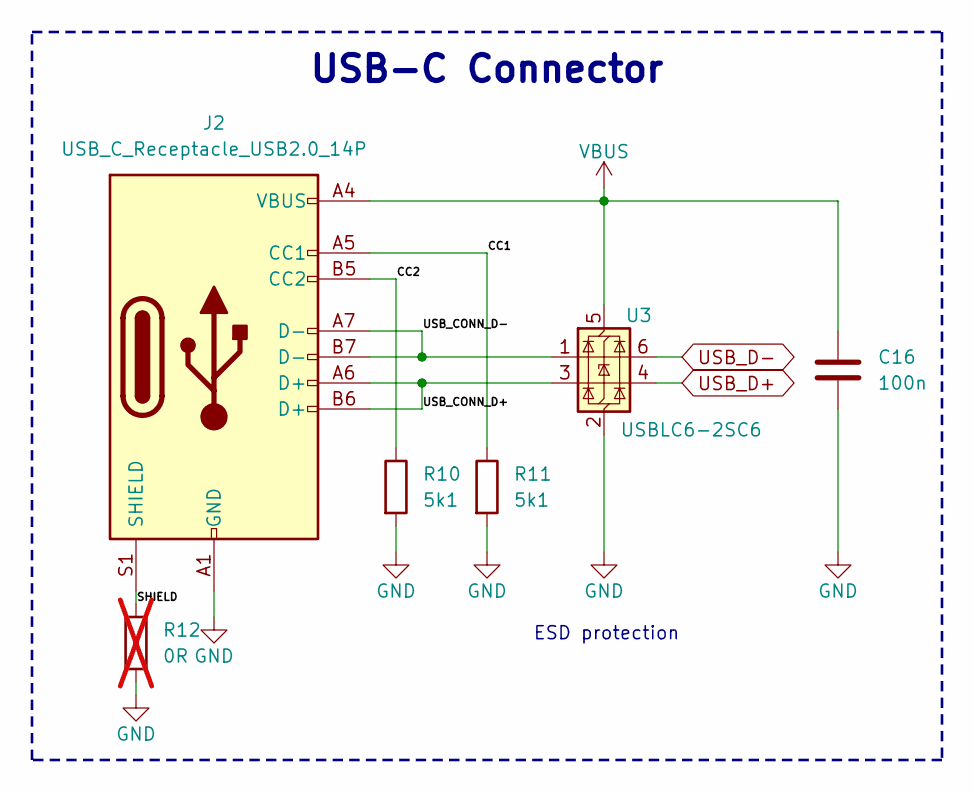
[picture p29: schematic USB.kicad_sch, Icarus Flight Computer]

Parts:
C16: 100n; C_0402_1005Metric; MPN C1525
J2: USB_C_Receptacle_USB2.0_14P; USB_C_Receptacle_G-Switch_GT-USB-7010ASV; MPN C2988369
R10, R11: 5k1; R_0402_1005Metric; MPN C25905
R12: 0R; R_0805_2012Metric; not fitted
U3: USBLC6-2SC6; SOT-23-6; MPN C7519

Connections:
/USB/CC1: J2.A5 (CC1), R11.1
/USB/CC2: J2.B5 (CC2), R10.1
/USB/SHIELD: J2.S1 (SHIELD), R12.1
/USB/USB_CONN_D+: J2.A6 (D+), J2.B6 (D+), U3.3 (I/O2)
/USB/USB_CONN_D-: J2.A7 (D-), J2.B7 (D-), U3.1 (I/O1)
GND: C16.2, J2.A1 (GND), J2.A12 (GND), J2.B1 (GND), J2.B12 (GND), R10.2, R11.2, R12.2, U3.2 (GND); also elsewhere on the board
USB_D+: U3.4 (I/O2); also elsewhere on the board
USB_D-: U3.6 (I/O1); also elsewhere on the board
VBUS: C16.1, J2.A4 (VBUS), J2.A9 (VBUS), J2.B4 (VBUS), J2.B9 (VBUS), U3.5 (VBUS); also elsewhere on the board

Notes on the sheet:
ESD protection
USB-C Connector

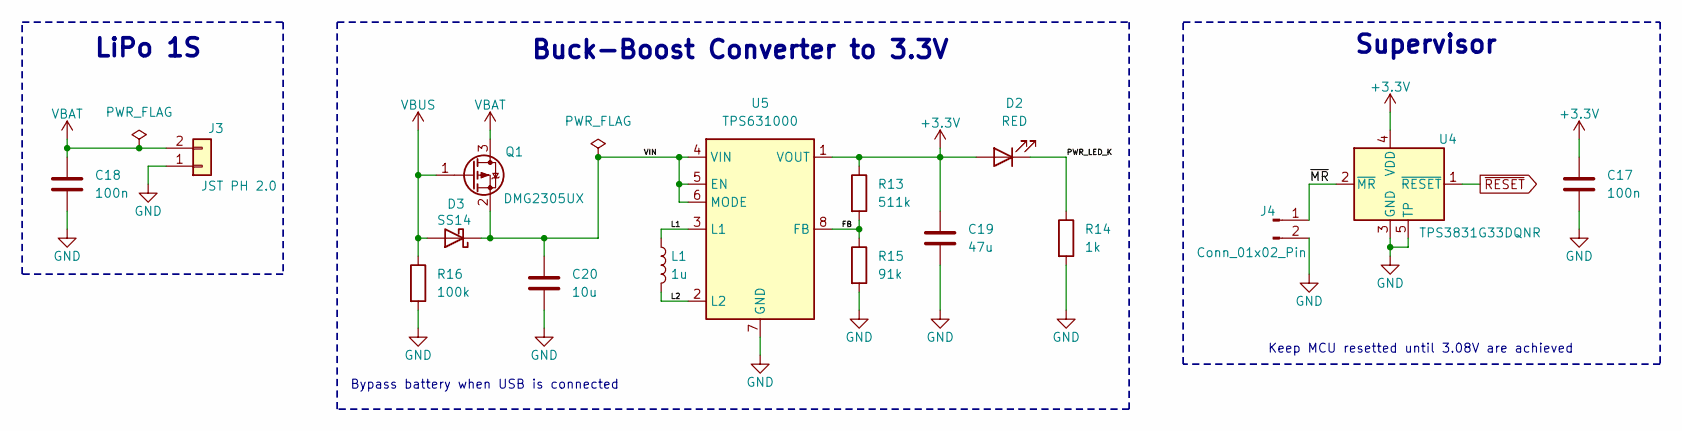
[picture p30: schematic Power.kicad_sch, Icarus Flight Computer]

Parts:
C17, C18: 100n; C_0402_1005Metric; MPN C1525
C19: 47u; C_0805_2012Metric; MPN C471380
C20: 10u; C_0603_1608Metric; MPN C90053
D2: RED; LED_0805_2012Metric; MPN C84256
D3: SS14; D_SMA; MPN C47460
J3: JST PH 2.0; JST_PH_B2B-PH-K_1x02_P2.00mm_Vertical; MPN C2683610
J4: Conn_01x02_Pin; PinHeader_1x02_P2.54mm_Vertical; MPN C492401
L1: 1u; L_1008_2520Metric; MPN C882955
Q1: DMG2305UX; SOT-23; MPN C150470
R13: 511k; R_0402_1005Metric; MPN C64042
R14: 1k; R_0402_1005Metric; MPN C11702
R15: 91k; R_0402_1005Metric; MPN C4147
R16: 100k; R_0402_1005Metric; MPN C25741
U4: TPS3831G33DQNR; Texas_X2SON-4_1x1mm_P0.65mm; MPN C2066649
U5: TPS631000; SOT-583-8; MPN C5219190

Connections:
+3.3V: C17.1, C19.1, D2.2 (A), R13.1, U4.4 (VDD), U5.1 (VOUT); also elsewhere on the board
/Power/FB: R13.2, R15.1, U5.8 (FB)
/Power/L1: L1.1, U5.3 (L1)
/Power/L2: L1.2, U5.2 (L2)
/Power/PWR_LED_K: D2.1 (K), R14.1
/Power/VIN: C20.1, D3.1 (K), Q1.2 (S), U5.4 (VIN), U5.5 (EN), U5.6 (MODE)
/Power/~MR: J4.1, U4.2 (~MR)
GND: C17.2, C18.2, C19.2, C20.2, J3.1, J4.2, R14.2, R15.2, R16.2, U4.3 (GND), U4.5 (TP), U5.7 (GND); also elsewhere on the board
VBAT: C18.1, J3.2, Q1.3 (D)
VBUS: D3.2 (A), Q1.1 (G), R16.1; also elsewhere on the board
~RESET: U4.1 (~RESET); also elsewhere on the board

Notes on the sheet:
Buck-Boost Converter to 3.3V
Keep MCU resetted until 3.08V are achieved
Supervisor
LiPo 1S
Bypass battery when USB is connected

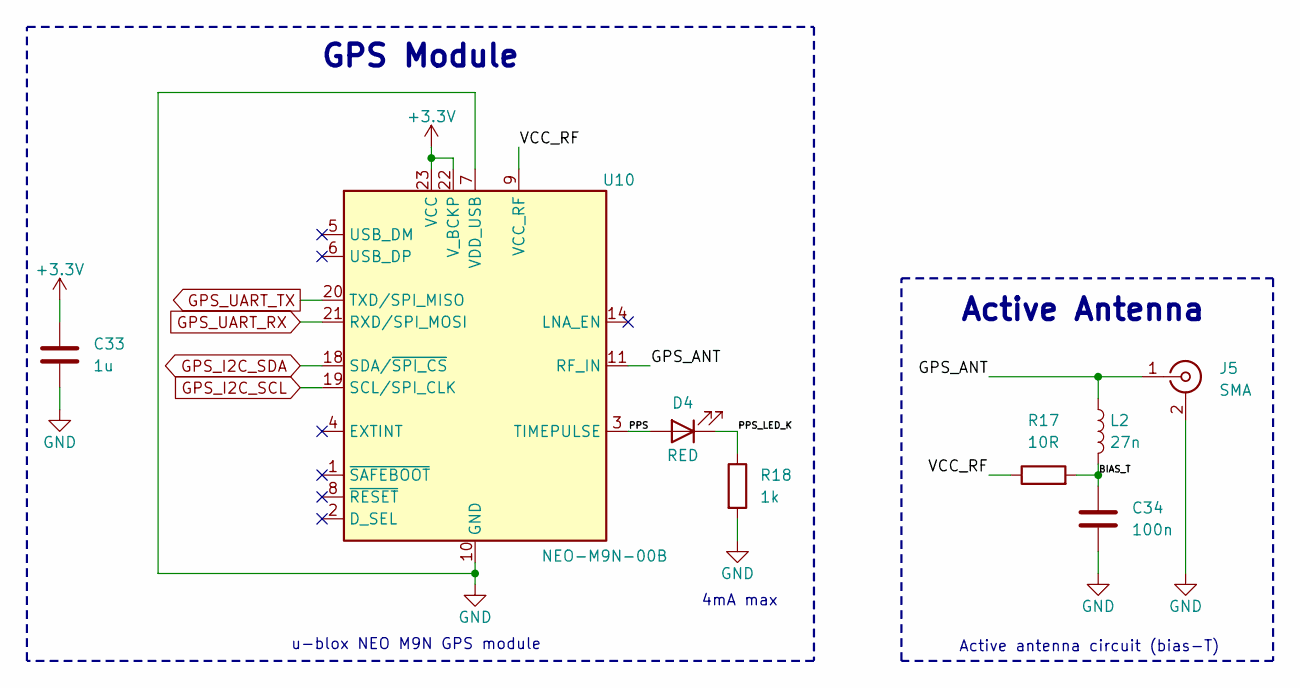
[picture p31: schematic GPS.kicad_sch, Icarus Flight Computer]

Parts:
C33: 1u; C_0603_1608Metric; MPN C59782
C34: 100n; C_0402_1005Metric; MPN C1525
D4: RED; LED_0805_2012Metric; MPN C84256
J5: SMA; SMA_Amphenol_132134_Vertical; MPN C3174425
L2: 27n; L_0402_1005Metric; MPN C12669
R17: 10R; R_1206_3216Metric; MPN C25349
R18: 1k; R_0402_1005Metric; MPN C11702
U10: NEO-M9N-00B; ublox_NEO; MPN C5119087

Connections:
+3.3V: C33.1, U10.22 (V_BCKP), U10.23 (VCC); also elsewhere on the board
/GPS/BIAS_T: C34.1, L2.2, R17.2
/GPS/GPS_ANT: J5.1 (In), L2.1, U10.11 (RF_IN)
/GPS/PPS: D4.2 (A), U10.3 (TIMEPULSE)
/GPS/PPS_LED_K: D4.1 (K), R18.1
/GPS/VCC_RF: R17.1, U10.9 (VCC_RF)
GND: C33.2, C34.2, J5.2 (Ext), R18.2, U10.7 (VDD_USB), U10.10 (GND), U10.12 (GND), U10.13 (GND), U10.24 (GND); also elsewhere on the board
GPS_I2C_SCL: U10.19 (SCL/SPI_CLK); also elsewhere on the board
GPS_I2C_SDA: U10.18 (SDA/~SPI_CS); also elsewhere on the board
GPS_UART_RX: U10.21 (RXD/SPI_MOSI); also elsewhere on the board
GPS_UART_TX: U10.20 (TXD/SPI_MISO); also elsewhere on the board

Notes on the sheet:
Active antenna circuit (bias-T)
u-blox NEO M9N GPS module
4mA max
Active Antenna
GPS Module

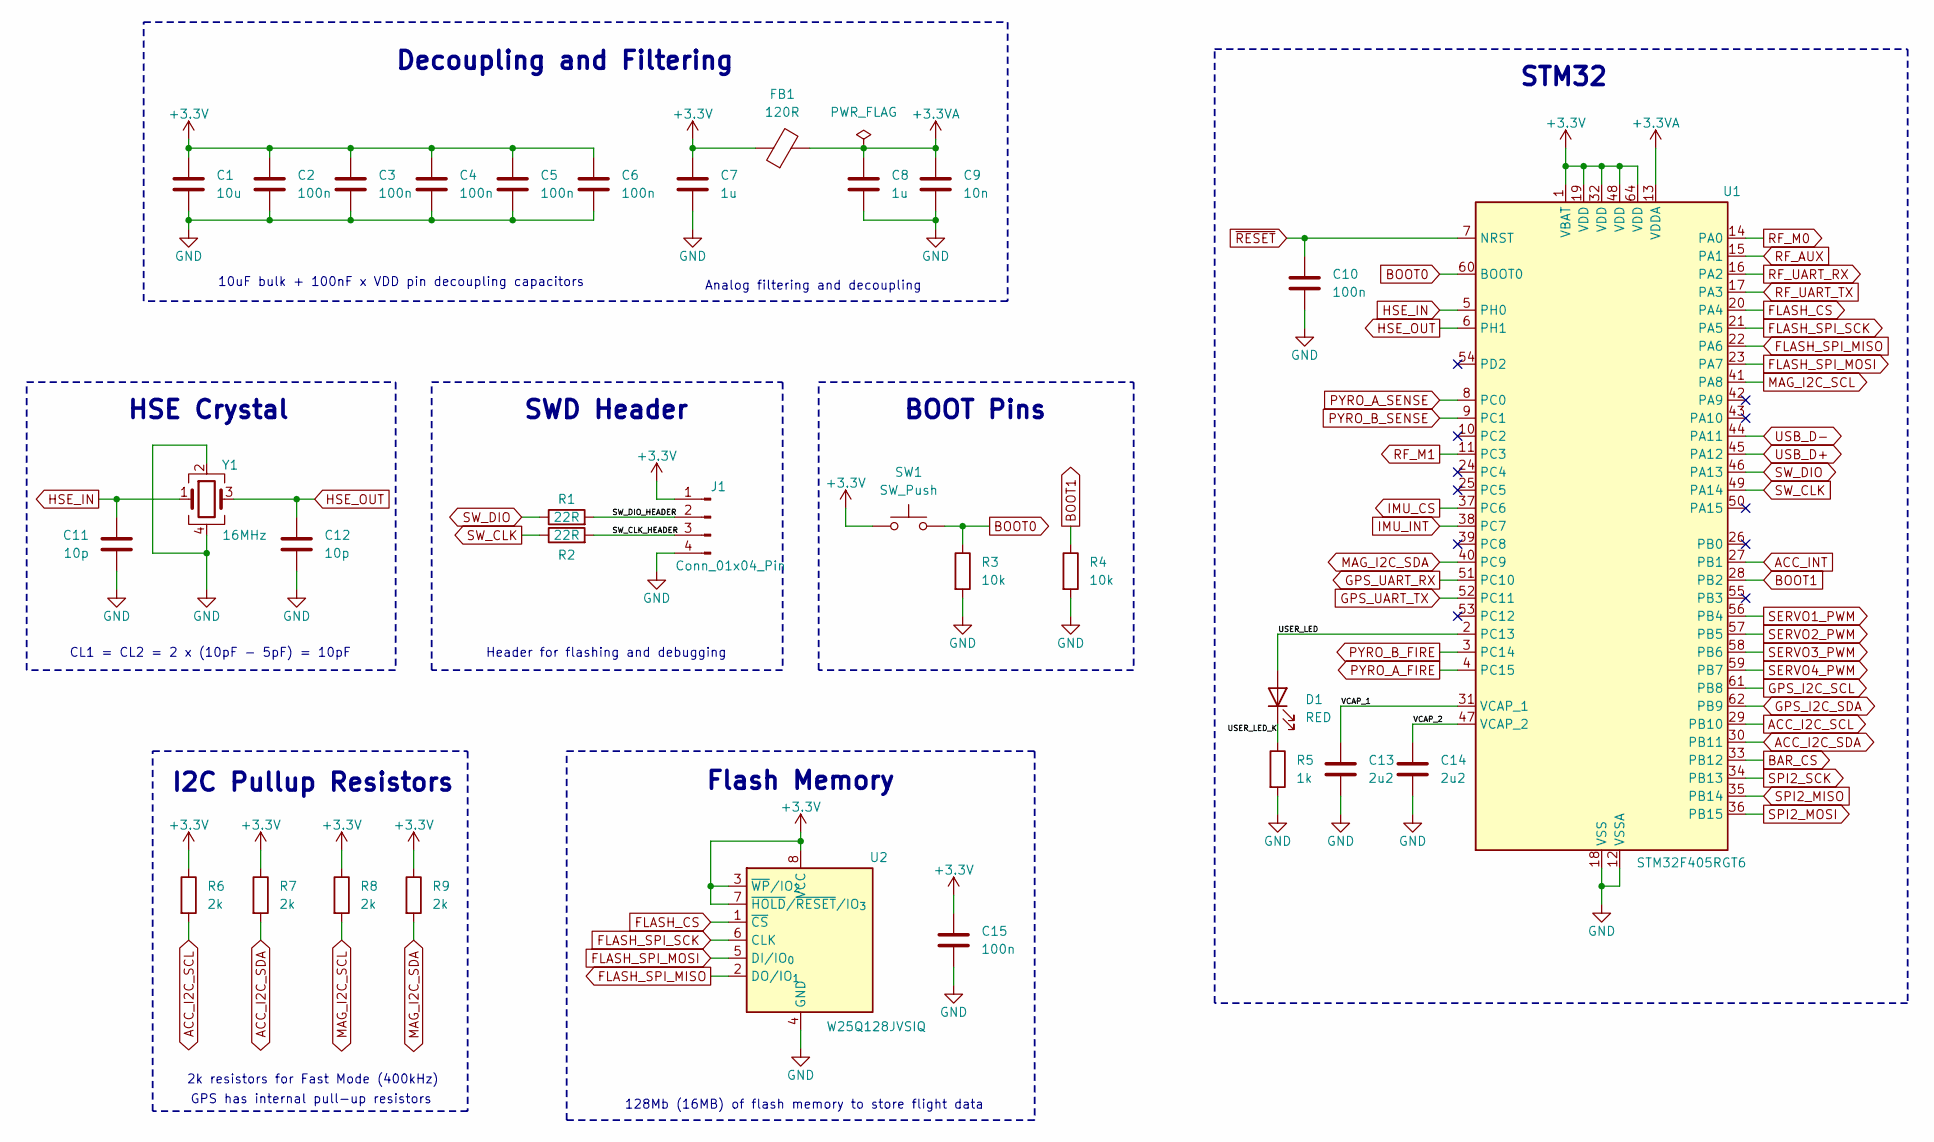
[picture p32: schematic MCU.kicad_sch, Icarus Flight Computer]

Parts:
C1: 10u; C_0805_2012Metric; MPN C95841
C2, C3, C4, C5, C6, C10, C15: 100n; C_0402_1005Metric; MPN C1525
C7, C8: 1u; C_0603_1608Metric; MPN C59782
C9: 10n; C_0402_1005Metric; MPN C318577
C11, C12: 10p; C_0402_1005Metric; MPN C32949
C13, C14: 2u2; C_0603_1608Metric; MPN C23630
D1: RED; LED_0805_2012Metric; MPN C84256
FB1: 120R; L_0603_1608Metric; MPN C85831
J1: Conn_01x04_Pin; PinHeader_1x04_P2.54mm_Vertical; MPN C2691448
R1, R2: 22R; R_0402_1005Metric; MPN C25092
R3, R4: 10k; R_0402_1005Metric; MPN C25531
R5: 1k; R_0402_1005Metric; MPN C11702
R6, R7, R8, R9: 2k; R_0402_1005Metric; MPN C4109
SW1: SW_Push; SW_TS-1088-AR02016; MPN C720477
U1: STM32F405RGT6; LQFP-64_10x10mm_P0.5mm; MPN C15742
U2: W25Q128JVSIQ; SOIC-8_5.3x5.3mm_P1.27mm; MPN C97521
Y1: 16MHz; Crystal_SMD_3225-4Pin_3.2x2.5mm; MPN C112972

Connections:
+3.3V: C1.1, C2.1, C3.1, C4.1, C5.1, C6.1, C7.1, C15.1, FB1.1, J1.1, R6.1, R7.1, R8.1, R9.1, SW1.1, U1.1 (VBAT), U1.19 (VDD), U1.32 (VDD), U1.48 (VDD), U1.64 (VDD), U2.3 (~WP/IO_{2}), U2.7 (~HOLD/~RESET/IO_{3}), U2.8 (VCC); also elsewhere on the board
+3.3VA: C8.1, C9.1, FB1.2, U1.13 (VDDA)
/MCU/SW_CLK_HEADER: J1.3, R2.2
/MCU/SW_DIO_HEADER: J1.2, R1.2
/MCU/USER_LED: D1.2 (A), U1.2 (PC13)
/MCU/USER_LED_K: D1.1 (K), R5.1
/MCU/VCAP_1: C13.1, U1.31 (VCAP_1)
/MCU/VCAP_2: C14.1, U1.47 (VCAP_2)
ACC_I2C_SCL: R6.2, U1.29 (PB10); also elsewhere on the board
ACC_I2C_SDA: R7.2, U1.30 (PB11); also elsewhere on the board
ACC_INT: U1.27 (PB1); also elsewhere on the board
BAR_CS: U1.33 (PB12); also elsewhere on the board
BOOT0: R3.1, SW1.2, U1.60 (BOOT0)
BOOT1: R4.1, U1.28 (PB2)
FLASH_CS: U1.20 (PA4), U2.1 (~CS)
FLASH_SPI_MISO: U1.22 (PA6), U2.2 (DO/IO_{1})
FLASH_SPI_MOSI: U1.23 (PA7), U2.5 (DI/IO_{0})
FLASH_SPI_SCK: U1.21 (PA5), U2.6 (CLK)
GND: C1.2, C2.2, C3.2, C4.2, C5.2, C6.2, C7.2, C8.2, C9.2, C10.2, C11.2, C12.2, C13.2, C14.2, C15.2, J1.4, R3.2, R4.2, R5.2, U1.12 (VSSA), U1.18 (VSS), U1.63 (VSS), U2.4 (GND), Y1.2, Y1.4; also elsewhere on the board
GPS_I2C_SCL: U1.61 (PB8); also elsewhere on the board
GPS_I2C_SDA: U1.62 (PB9); also elsewhere on the board
GPS_UART_RX: U1.51 (PC10); also elsewhere on the board
GPS_UART_TX: U1.52 (PC11); also elsewhere on the board
HSE_IN: C11.1, U1.5 (PH0), Y1.1
HSE_OUT: C12.1, U1.6 (PH1), Y1.3
IMU_CS: U1.37 (PC6); also elsewhere on the board
IMU_INT: U1.38 (PC7); also elsewhere on the board
MAG_I2C_SCL: R8.2, U1.41 (PA8); also elsewhere on the board
MAG_I2C_SDA: R9.2, U1.40 (PC9); also elsewhere on the board
PYRO_A_FIRE: U1.4 (PC15); also elsewhere on the board
PYRO_A_SENSE: U1.8 (PC0); also elsewhere on the board
PYRO_B_FIRE: U1.3 (PC14); also elsewhere on the board
PYRO_B_SENSE: U1.9 (PC1); also elsewhere on the board
RF_AUX: U1.15 (PA1); also elsewhere on the board
RF_M0: U1.14 (PA0); also elsewhere on the board
RF_M1: U1.11 (PC3); also elsewhere on the board
RF_UART_RX: U1.16 (PA2); also elsewhere on the board
RF_UART_TX: U1.17 (PA3); also elsewhere on the board
SERVO1_PWM: U1.56 (PB4); also elsewhere on the board
SERVO2_PWM: U1.57 (PB5); also elsewhere on the board
SERVO3_PWM: U1.58 (PB6); also elsewhere on the board
SERVO4_PWM: U1.59 (PB7); also elsewhere on the board
SPI2_MISO: U1.35 (PB14); also elsewhere on the board
SPI2_MOSI: U1.36 (PB15); also elsewhere on the board
SPI2_SCK: U1.34 (PB13); also elsewhere on the board
SW_CLK: R2.1, U1.49 (PA14)
SW_DIO: R1.1, U1.46 (PA13)
USB_D+: U1.45 (PA12); also elsewhere on the board
USB_D-: U1.44 (PA11); also elsewhere on the board
~RESET: C10.1, U1.7 (NRST); also elsewhere on the board

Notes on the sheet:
Analog filtering and decoupling
I2C Pullup Resistors
STM32
Flash Memory
HSE Crystal
GPS has internal pull-up resistors
BOOT Pins
CL1 = CL2 = 2 x (10pF - 5pF) = 10pF
10uF bulk + 100nF x VDD pin decoupling capacitors
128Mb (16MB) of flash memory to store flight data
2k resistors for Fast Mode (400kHz)
SWD Header
Decoupling and Filtering
Header for flashing and debugging

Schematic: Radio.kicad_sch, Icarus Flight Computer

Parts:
C35: 10u; C_0805_2012Metric; MPN C95841
C36: 100n; C_0402_1005Metric; MPN C1525
U11: E220-900T22S; E220-xxxT22S; MPN C970285

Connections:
+3.3V: C35.1, C36.1, U11.25 (VCC); also elsewhere on the board
GND: C35.2, C36.2, U11.2 (GND), U11.8 (GND), U11.11 (GND), U11.13 (GND), U11.14 (GND), U11.15 (GND), U11.16 (GND), U11.19 (GND), U11.26 (GND); also elsewhere on the board
RF_AUX: U11.24 (AUX); also elsewhere on the board
RF_M0: U11.20 (M0); also elsewhere on the board
RF_M1: U11.21 (M1); also elsewhere on the board
RF_UART_RX: U11.22 (RXD); also elsewhere on the board
RF_UART_TX: U11.23 (TXD); also elsewhere on the board

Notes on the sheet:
62.5kbps LoRa communication module
LoRa Radio

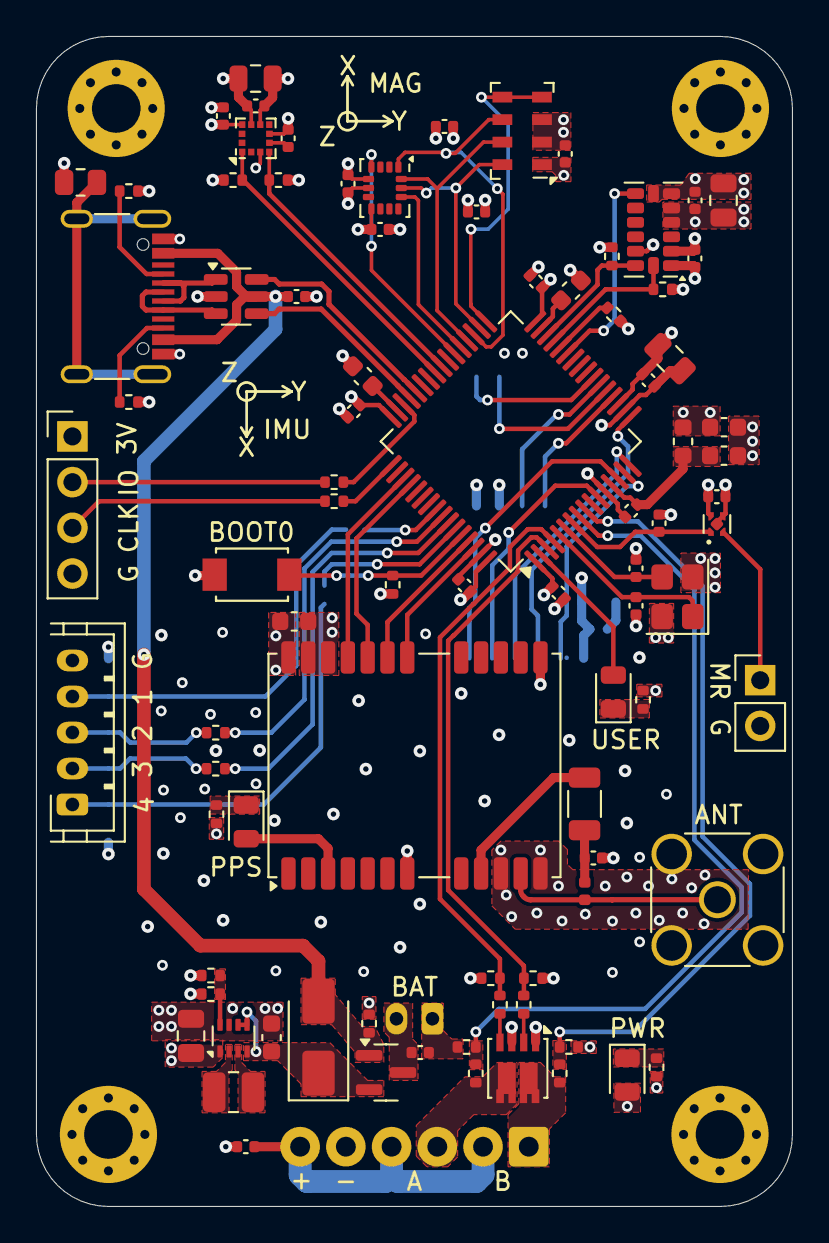
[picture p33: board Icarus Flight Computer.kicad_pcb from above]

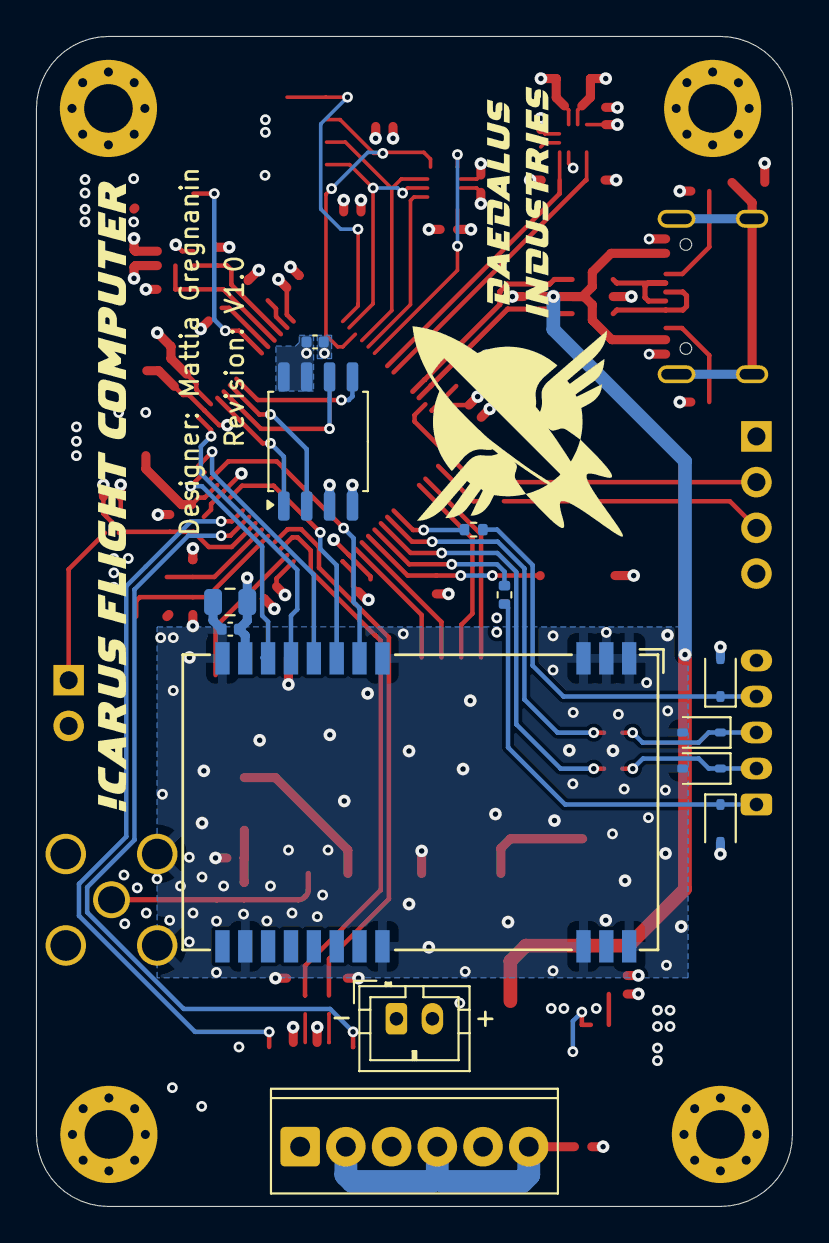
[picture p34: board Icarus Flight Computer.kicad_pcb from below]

Board: 4 copper layers, 42.0 x 65.0 mm, 104 parts (13 on the bottom side), 78 nets.

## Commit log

2025-05-07 Added Docs folder
    [Icarus Flight Computer.kicad_pcb, MCU.kicad_sch]
2025-05-16 Made board smaller
    [GPS.kicad_sch, Icarus Flight Computer.kicad_pcb, Icarus Flight Computer.kicad_sch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]
2025-06-03 Added README.md with photos
    [Icarus Flight Computer.step]
